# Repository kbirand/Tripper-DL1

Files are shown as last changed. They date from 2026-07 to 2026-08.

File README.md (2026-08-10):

# Tripper Puck (DL1)

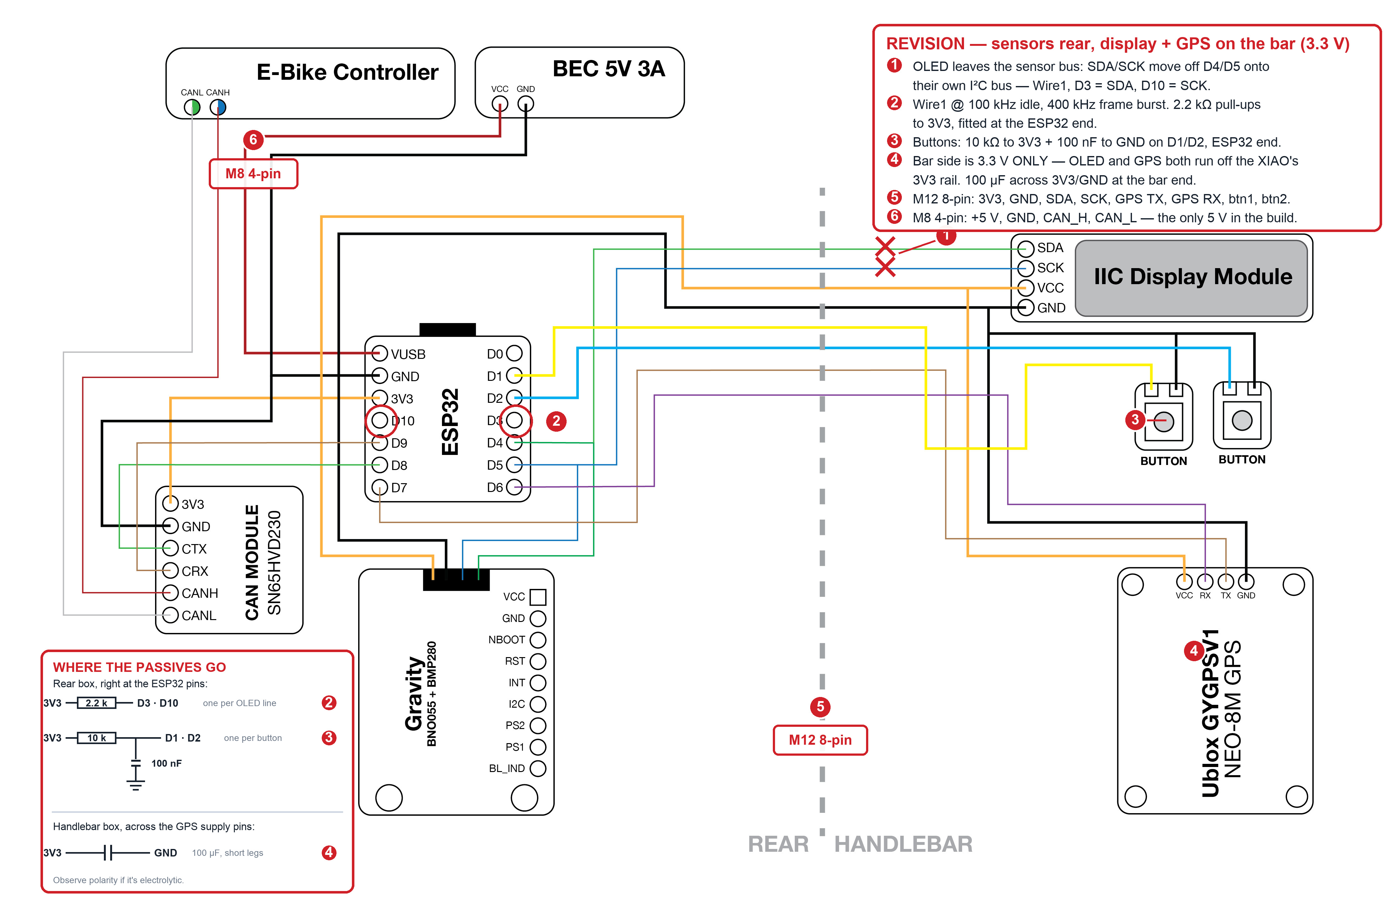
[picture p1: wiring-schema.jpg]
Tripper Puck wiring schematic — ESP32-S3 with the SN65HVD230 CAN transceiver, Gravity 10DOF, NEO-8M GPS, SSD1306 OLED and two buttons, powered from the bike through a 5 V BEC. Split across two enclosures: sensors and CAN at the rear, display, GPS and buttons at the handlebar


The red callouts on the schematic mark the handlebar-split revision — the base
drawing still routes the OLED to D4/D5, which is superseded. Read the notes.

An editable version lives in [`hardware/tripper-puck.fzz`](hardware/tripper-puck.fzz)
(Fritzing). Every part is custom and embedded in the file, so it opens without
installing anything into your parts bin. The nets are the source of truth; the
part placement is machine-generated and worth tidying before you print it.

A matchbox-sized BLE telemetry puck for e-bikes — companion hardware for the
[Tripper iOS app](https://github.com/kbirand/Tripper). It streams on-chip-fused
IMU orientation and barometric data to the phone over Bluetooth LE, and reads
the bike's own CAN bus listen-only for battery, drivetrain and rider-control
data; the app records, analyzes, and exports. The puck itself is stateless: it
powers from the bike through a 5 V BEC and boots in seconds.

It comes in **two builds** that share one codebase and one BLE contract:

- **[Light build](#1--light-build)** — four parts in one box at the rear.
  IMU, barometer and bike CAN. The phone supplies position; the app is the UI.
- **[Full build](#2--full-build)** — adds a handlebar module: 5 Hz GPS, a
  0.91" OLED and two buttons. Strictly additive, so Light upgrades to Full
  without rewiring anything.

See [Choosing a build](#choosing-a-build) for the trade-offs.

**Status:** bench-complete and phone-verified (2026-07-21). Remaining:
Tripper-side `ExternalSensorSource` (Swift), enclosure, field ride.

## How it works

- **No battery** — a 5 V BEC steps the bike's pack down to VUSB; boots with
  the bike
- **No SD card** — the phone is the recorder; BLE is the only data path
- **No screen dependence** — the OLED is a convenience dashboard and every
  feature works headless. The Light build is exactly that claim taken to its
  conclusion: no screen at all, nothing lost from the recording
- **Mount-zero calibration** — the current orientation becomes 0/0/0 (reference
  quaternion, persisted to flash, survives reboots, applied to both display and
  telemetry). Triggered by a 10 s button hold on Full, or *Zero pitch & roll*
  in the app on either build
- **Ride awareness** — the app pushes ride state, so link flaps and mid-ride
  reboots heal themselves. On Full this inverts the OLED and adds a trip-time
  screen; on Light it is simply acknowledged
- **Reads the bike** — listen-only CAN gives battery percentage, pack voltage,
  cell balance, motor current and rider controls without touching the bus

## Choosing a build

Two configurations, one codebase, one BLE contract:

| | **Light build** | **Full build** |
|---|---|---|
| Physical form | one box at the rear | rear box **+ handlebar module** |
| Sensing | IMU, barometer, bike CAN | IMU, barometer, bike CAN, **GPS** |
| Display | none — the app is the UI | **0.91" OLED**, 4 screens |
| Buttons | none — the app sends control writes | **two** (screens · marker/zero) |
| Position from | the **phone's** GPS | the puck's own **5 Hz** GPS |
| Firmware | [`tripper_light`](hardware/firmware/tripper_light/) | [`tripper_puck`](hardware/firmware/tripper_puck/) |
| Parts | 4 | 8 |
| Wires to run | 6 | 14 |

**Start with the Light build.** It is the entire telemetry product — fused
orientation, g-force, barometric altitude and every decoded bike-CAN signal —
in four parts and one enclosure, and your phone already carries a GPS the app
already reads. The Full build buys 5 Hz position (the phone's is 1 Hz), a
dashboard you can read with the phone pocketed, and two hardware buttons.

**The Full build is strictly additive.** Nothing in the Light build gets
rewired to get there: the handlebar parts land on pins the Light build leaves
free, so it is an upgrade path rather than a different project.

The BLE packets are **byte-identical** across both, so the app needs no branch.
A Light puck reports its GPS block as invalid — the same state a Full puck
reports before it gets a fix, which the app already has to handle — and the
status packet's [capability byte](#status-packet-14-bytes) says which build is
on the other end.

## 1 · Light build

MCU, sensor board, CAN transceiver, power. One enclosure at the rear of the
bike; nothing on the handlebar.

| Part | Role |
|---|---|
| Seeed XIAO ESP32-S3 | MCU, BLE 5.0, on-chip TWAI CAN controller |
| DFRobot Gravity 10DOF (BNO055 + BMP280) | On-chip sensor fusion + barometer, I²C |
| SN65HVD230 CAN transceiver | 3.3 V CAN PHY for the bike bus, D8/D9 |
| 5 V BEC (3 A) | Steps the bike's pack down to 5 V, feeds VUSB |

No SD card, no LiPo, no power switch, no status LED, no screen — the phone is
the recorder *and* the interface over BLE, and the bike is the power source.

What you give up versus Full: no on-board position (the app uses phone GPS, so
rides still record), no glanceable display, and marker/mount-zero move to
[control writes](#control-opcodes) instead of buttons.

### Pin map — Light build

| Pin | Function |
|---|---|
| D4 / D5 | I²C SDA / SCL — BNO055 `0x28`, BMP280 `0x76` @ 100 kHz |
| D8 / D9 | CAN TX→CTX / RX←CRX (SN65HVD230), 250 kbit/s listen-only |
| D0, D1, D2, D3, D6, D7, D10 | free — D1, D2, D6, D7 are what the Full build claims |

I²C sits on the XIAO's **default pads**, so a bare `Wire.begin()` would work; the
firmware still names them explicitly via `PIN_SDA`/`PIN_SCL` so the pin map lives
in one place.

> **Troubleshooting — if every I²C device looks dead at once.** The first board
> used in this project had its **D4 pad clamped low**: it read 0 even with the
> internal pull-up enabled and nothing attached, shorted to ground somewhere on
> the board. An I²C line that cannot idle high is a bus no device can ever
> signal on, so it presents as *four* simultaneously dead sensors rather than
> one bad pin — which is why it is worth recognising. SDA was moved to D3 as a
> workaround until the board was replaced.
>
> To tell a dead pad from a wiring fault: pull the pin up, then down, and read
> it back. A pad the chip still controls follows both (1 then 0); one that reads
> 0 against the pull-up is tied to ground by something outside the GPIO.
> `padSweep()` in [`bench_imu_can`](hardware/firmware/bench_imu_can/) does this
> across the whole pad row every boot — one pin failing where six neighbours
> pass is the diagnosis — and
> [`i2c_diag`](hardware/firmware/i2c_diag/) localises it further.

### Wiring — Light build

Pin columns match the physical XIAO ESP32-S3 viewed from above, USB-C at
the top. Six wires plus the two CAN taps:

```
                          USB-C (top edge) — flashing only
                      ┌───────────────────────┐
 n/c ─────────────────┤ D0                 5V ├──◄ BEC +5V ◄─ BEC 5V 3A ◄─ bike pack
 n/c (Full: button 1) ┤ D1                GND ├────────● GND rail ◄ BEC GND
 n/c (Full: button 2) ┤ D2                3V3 ├────────● 3V3 rail
 n/c ─────────────────┤ D3                D10 ├─ n/c
 SDA bus ●────────────┤ D4                 D9 ├──────◄ CAN CRX
 SCL bus ●────────────┤ D5                 D8 ├──────► CAN CTX
 n/c (Full: GPS TX) ──┤ D6 (TX)       (RX) D7 ├─ n/c (Full: GPS RX)
                      └───────────────────────┘
                            XIAO ESP32-S3

 ● 3V3 rail ─┬─ Gravity 10DOF VCC (red)      ● SDA bus (D4) ── Gravity SDA (blue)
             └─ CAN module 3V3
                                             ● SCL bus (D5) ── Gravity SCL (green)
 ● GND rail ─┬─ Gravity 10DOF GND (black)
             └─ CAN module GND

 CAN module CANH ──◄ bike CAN_H          (2-pin connector — see the CAN section)
 CAN module CANL ──◄ bike CAN_L
```

## 2 · Full build

Everything in the Light build, plus a handlebar module: GPS for 5 Hz position,
an OLED for at-a-glance status, and two buttons. The GPS wants sky view and the
screen wants your eyeline, which is why these four live at the bars while the
MCU, sensor board and CAN transceiver stay in the rear box.

| Part it adds | Role |
|---|---|
| u-blox NEO-8M GPS (GYGPSV1 carrier) | 5 Hz position/speed/time, UART @ 115200 |
| SSD1306 0.91" OLED 128×32 | Clock / live-data / bike-CAN screens + all status, I²C `0x3C` |
| 12 mm button | Screen step / auto-cycle toggle |
| HW-483 button | Marker (click) / attitude zero (hold) |

### Pin map — additions

Only free pins are used, so the Light build's wiring is untouched:

| Pin | Function |
|---|---|
| D1 | Screen button → GND (internal pull-up) |
| D2 | Marker/zero button → GND (internal pull-up) |
| D6 / D7 | UART TX→GPS RX / RX←GPS TX @ 115200 |
| D3 / D10 | I²C bus 1 (`Wire1`) SDA / SCL — SSD1306 OLED `0x3C`. **Runs to the handlebar** |

The Light build's D4/D5 bus is untouched and stays **rear-enclosure only**: the
OLED gets its own bus rather than joining it.

**Two I²C buses, on purpose.** The sensors and the display sit in different
enclosures about a metre apart, so they get separate buses. Bus 0 stays short
— 15 cm inside the rear box — because the BNO055's clock-stretching already
forces it to **100 kHz** (validated: 59,722 reads / 0 errors / 10 min) and it
is the one bus whose failure costs real data. Bus 1 carries only the OLED out
to the handlebar; a metre of cable there can glitch the screen but can no
longer touch sensor fusion. Wire1 idles at 100 kHz and bursts frames at
400 kHz (`OLED_BUS_HZ` / `OLED_BURST_HZ` in the firmware) — if a long or
unshielded run tears the display, drop the burst to 100 kHz first.

### Wiring — Full build

Same as the Light build with the handlebar module added. The four new parts land on the
pins the Light build left free, so nothing already wired moves:

Signals marked **⇢ bar** leave the rear enclosure through the 8-pin handlebar
connector; everything else stays inside the rear box.

```
                          USB-C (top edge) — flashing only
                      ┌───────────────────────┐
 n/c ─────────────────┤ D0                 5V ├──◄ BEC +5V ◄─ BEC 5V 3A ◄─ bike pack
 Screen button ⇢ bar ─┤ D1                GND ├────────● GND rail ◄ BEC GND
 Marker/Zero  ⇢ bar ──┤ D2                3V3 ├────────● 3V3 rail
 OLED SDA     ⇢ bar ──┤ D3                D10 ├── OLED SCK  ⇢ bar
 Sensor SDA ●─────────┤ D4                 D9 ├──────◄ CAN CRX
 Sensor SCL ●─────────┤ D5                 D8 ├──────► CAN CTX
 to GPS RX  ⇢ bar ◄───┤ D6 (TX)       (RX) D7 ├──────◄ from GPS TX  ⇢ bar
                      └───────────────────────┘
                            XIAO ESP32-S3

 REAR enclosure                          HANDLEBAR enclosure
 ──────────────                          ───────────────────
 ● 3V3 rail ─┬─ Gravity 10DOF VCC (red)  OLED VCC / GND / SDA / SCK
             ├─ CAN module 3V3           GPS  VCC / GND / TX / RX
             └─── 3V3 ⇢ bar              Screen button ○ ─┐
                                         Marker/Zero   ○ ─┴─ to GND ⇢ bar
 ● Sensor SDA (D4) ── Gravity SDA (blue)
 ● Sensor SCL (D5) ── Gravity SCL (green)   ┌── 100 µF bulk cap across
                                            │   3V3/GND at this end
 ● GND rail ─┬─ Gravity 10DOF GND (black)  ─┘
             ├─ CAN module GND
             └─── GND ⇢ bar

 8-pin handlebar harness (M12 A-coded)
   1 3V3   2 GND   3 OLED SDA (D3)   4 OLED SCK (D10)
   5 GPS RX (◄D6)  6 GPS TX (►D7)    7 btn1 (D1)   8 btn2 (D2)
```

Wiring notes (both builds unless noted):

- **Power comes from a 5 V BEC**, not USB. The BEC steps the bike's traction
  pack down to 5 V / 3 A and feeds the XIAO's 5V (VUSB) pin. USB-C is only for
  flashing — **never plug USB in while the BEC is powered**: both drive VUSB
  and the two 5 V rails collide. Unplug one before the other.
- **GPS UART is a crossover** *(Full only)* — XIAO TX (D6) feeds the GPS **RX**
  pin and vice versa. If the firmware reports "no NMEA data", these two are
  swapped. Note the CAN pair on D8/D9 is *not* a crossover: CTX→CTX, CRX→CRX.
- **Buttons need external pull-ups now that they're a metre away** *(Full
  only)*. Each still connects its pin straight to GND and the firmware still
  enables the internal pull-up — but that pull-up is ~45 kΩ, and a metre of
  wire on a high-impedance input is an antenna for BEC and motor-controller
  switching noise. Add a **10 kΩ to 3V3 and a 100 nF to GND at the ESP32 end**
  of D1 and D2. On a breadboard with short leads you can skip this; on the bike
  you cannot.
- **The Gravity board's I²C comes from its 4-pin socket** (its back-side
  pad row is control pins only — no SDA/SCL there). Trim the cable to
  length and glue-lock the connector for vibration.
- **The handlebar box is 3.3 V only.** Both things in it — the SSD1306 and the
  NEO-8M carrier — run off the XIAO's own 3V3 regulator; the only 5 V anywhere
  in the build is the BEC feeding VUSB inside the rear box. Never run 5 V up to
  the bar. This also raises the stakes on the two rules below: there is no
  regulator at the far end to absorb cable drop, so whatever the metre of wire
  loses comes straight out of the GPS's supply margin.
- **The handlebar run** carries 8 conductors (see the harness table above) over
  roughly a metre. Rules for it:
  - **Shielded multicore**, shield to GND **at the rear end only** — grounding
    both ends makes a loop.
  - **SDA and SCL each twisted with their own GND return**, never twisted with
    each other; paired together they crosstalk. Same for GPS TX/RX.
  - **2.2 kΩ pull-ups on the OLED bus**, fitted at the ESP32 end, replacing the
    module's own 4.7–10 kΩ. A metre of cable adds ~100 pF and the weaker
    pull-ups can't pull the edges up through it. Sizing, if your run is longer:
    the pull-up and the bus capacitance set the rise time, which must stay under
    1 µs at 100 kHz, while the sink current (3.3 V ÷ R) must stay under 3 mA.

    | Run | Bus C | 2.2 kΩ | 1.5 kΩ |
    |---|---|---|---|
    | 1 m | ~150 pF | 0.27 µs | 0.19 µs |
    | 2 m | ~250 pF | 0.7 µs | 0.45 µs |
    | 3 m | ~350 pF | 1.2 µs ✗ | 0.63 µs |

    So **2.2 kΩ to ~2 m, 1.5 kΩ (2.2 mA sink) to ~3 m.** Past 3 m the 400 pF
    bus-capacitance ceiling binds and no pull-up value saves it.
  - **100 µF bulk capacitor at the handlebar end**, across 3V3/GND near the GPS.
    Its acquisition current spikes into the cable's inductance otherwise sag
    the rail and lengthen time-to-fix.
  - **≥ 26 AWG** on the 3V3 and GND conductors. The bar end draws ~60 mA, which
    is only ~16 mV of drop at 26 AWG — but thin 30 AWG hookup wire more than
    doubles that, and it comes off a 3.3 V rail with no headroom to spare.
  - **Past 2 m, drop `OLED_BURST_HZ` to 100 kHz** and move to the 1.5 kΩ
    pull-ups. Don't reach for an I²C buffer (P82B715 / P82B96) — the arithmetic
    above says plain I²C covers any run a motorcycle actually needs, and both
    parts are out of stock domestically anyway (the P82B715 is obsolete).
  - **Keep the cable thin.** 8 × 0.14 mm² (≈26 AWG) shielded is ~6 mm OD and
    still flexible; 0.25 mm² and up gets stiff enough to fatigue at the steering
    head. 0.14 mm² carries the ~60 mA with room to spare.
- **GPS patch antenna**: sky-facing, ≥ 15 mm from the XIAO and USB cable —
  the ESP32's RF noise measurably delays fixes. Moving the GPS to the handlebar
  enclosure satisfies this for free, since the ESP32 stays at the rear.
- **GPS backup cell** (MS621 on the GY carrier): if it's flat, every power
  cycle factory-resets the module to 9600/1 Hz *and* forces a cold start
  (minutes to first fix instead of seconds). The firmware detects the revert
  and reconfigures automatically — boot log says `was at 9600 factory: BBR
  lost, check backup cell` — but only a healthy cell brings back hot starts.
  The cell trickle-charges while powered; if it never holds, replace it.

### Connectors

Two enclosures means two harnesses, and they are deliberately different sizes
so they cannot be cross-plugged.

| Run | Conductors | Connector |
|---|---|---|
| Bike → rear enclosure | +5 V, GND, CAN_H, CAN_L | **M8 4-pin**, IP67 |
| Rear → handlebar enclosure | **3V3**, GND, SDA, SCL, GPS TX, GPS RX, btn1, btn2 | **M12 8-pin A-coded**, IP67 |

The two runs carry different voltages — 5 V to the rear box, 3.3 V onward to the
bar — which is a second reason the connectors are deliberately different sizes.

**Gender follows the live side.** Whichever end stays energised when the pair
is separated gets the *female* sockets — recessed contacts can't be shorted
against the frame. On the bike run that's the cable (it goes back to the BEC),
so the rear enclosure carries a **male** panel receptacle and the cable carries
a **female** plug. The handlebar run is dead on both sides once the bike
connector is pulled, so either orientation is safe there; keep the panel male
for consistency.

Parts that work, sourced domestically (prices July 2026): rear panel
**ATTEND 219A-04MSR** ≈ ₺243, bike cable **SIGNAL ASM08AF04001** ≈ ₺282. If you
also want the BEC and CAN tap to separate from the 4-core, add
**ASM08AM04001** + a second **ASM08AF04001** — but note these field-assembly
bodies take a *single* cable gland, so the BEC pair and CAN pair must be merged
into one jacket before the connector either way. Unless that junction needs to
come apart, solder and adhesive-lined heat-shrink is more vibration-tolerant
and free.

**Keep the pin assignment identical at both ends of every run.** With two
connectors in the harness it is easy to mirror one and feed 5 V into CAN_H.

## Firmware

Arduino sketches in [`hardware/firmware/`](hardware/firmware/):

| Sketch | Purpose |
|---|---|
| [`tripper_light`](hardware/firmware/tripper_light/) | **Light-build firmware** — IMU + baro + CAN → BLE. No GPS/OLED/button code at all; marker and mount-zero arrive as control writes. Same UUIDs and same 88-byte packet as the Full build |
| [`tripper_puck`](hardware/firmware/tripper_puck/) | **Full-build firmware** — sensors + GPS → BLE + OLED |
| [`bench_imu_can`](hardware/firmware/bench_imu_can/) | Bring-up rig for a half-built puck — IMU + baro + CAN only, no OLED/buttons/GPS. Talks to the BNO055 registers directly (a library `begin()` can't tell a phantom ACK from a chip), counts every failed read, and re-probes missing sensors every 3 s so a wire soldered mid-run comes up on its own. Same BLE UUIDs and packets as production |
| [`i2c_gate`](hardware/firmware/i2c_gate/) | BNO055 clock-stretch stress test (the go/no-go gate) |
| [`i2c_diag`](hardware/firmware/i2c_diag/) | Wiring diagnostic — line states + normal/swapped bus scans |
| [`gps_config_5hz`](hardware/firmware/gps_config_5hz/) | One-time GPS config: 5 Hz + 115200, saved to BBR (production firmware re-applies at boot) |
| [`gps_revert_factory`](hardware/firmware/gps_revert_factory/) | Test harness — reverts the GPS to 9600/1 Hz factory defaults (simulates a power cycle with a dead backup cell) to exercise `gpsBringup()`'s recovery path |
| [`can_probe`](hardware/firmware/can_probe/) | CAN bring-up — decoded dashboard on the OLED and over BLE (`Tripper-CAN`, Nordic UART). Reports wirelessly on purpose: the bike and a USB host must never be connected at once |

### Build & flash

```sh
arduino-cli core install esp32:esp32

# Light build — no SSD1306 or TinyGPSPlus needed
arduino-cli lib install "Adafruit BNO055" "Adafruit BMP280 Library" "NimBLE-Arduino"
arduino-cli compile -b esp32:esp32:XIAO_ESP32S3 hardware/firmware/tripper_light
arduino-cli upload  -b esp32:esp32:XIAO_ESP32S3 -p /dev/cu.usbmodem* hardware/firmware/tripper_light

# Full build — adds the display and GPS libraries
arduino-cli lib install "Adafruit SSD1306" "TinyGPSPlus"
arduino-cli compile -b esp32:esp32:XIAO_ESP32S3 hardware/firmware/tripper_puck
arduino-cli upload  -b esp32:esp32:XIAO_ESP32S3 -p /dev/cu.usbmodem* hardware/firmware/tripper_puck
```

USB is needed exactly twice in a puck's life — the first flash of an
OTA-capable firmware, and recovery if an update bricks it. After that the puck
raises its own WiFi network on request and can be flashed from a laptop *or
straight from a phone browser* with the bike untouched; the last built image is
committed at [`releases/`](releases/) so no toolchain is needed at all.
**[`docs/flashing.md`](docs/flashing.md) is the complete reference** —
networks, passwords, both command lines, making a `.bin`, and which of the nine
build artifacts is the one you flash.

⚠️ **Never plug USB in while the BEC is powered, and never while the CAN pair
is spliced in** — see [Bike CAN bus](#bike-can-bus-talaria). Unplug the 2-pin
CAN connector or kill the BEC before flashing.

The two sketches keep duplicate copies of the packet structs, the CAN decode
and the UUIDs. That is deliberate — each is a standalone Arduino sketch — but
it means the two can drift. Anything touching the wire format must land in
both; this check should print nothing:

```sh
for f in tripper_puck tripper_light; do
  awk '/^struct __attribute__\(\(packed\)\) TelemetryPacket/,/^static_assert\(sizeof\(StatusPacket\)/' \
    hardware/firmware/$f/$f.ino | grep -E "^\s+(uint|int)[0-9_]+t\s" | sed 's|//.*||;s/[[:space:]]*$//' > /tmp/$f.f
done; diff /tmp/tripper_puck.f /tmp/tripper_light.f && echo "packets agree"
```

### Controls — Full build only

| Input | Action |
|---|---|
| Screen button (D1) click | Step to the next OLED screen |
| Screen button (D1) 3 s hold | Toggle auto-cycling (thin border = cycling) |
| Marker button (D2) click | Marker counter++ in telemetry · MARK splash |
| Marker button (D2) 10 s hold | Zero the mount at the current orientation (progress bar → ZEROED, or `ACC n/3` if the accelerometer isn't calibrated yet) |

The Light build has no buttons and no screen: markers arrive as control write
`0x01` and mount-zero as `0x02`, both from the app. Everything below describes
the Full build's display.

All status lives on the OLED. **Screens do not rotate on their own** — on a
moving bike the screen you picked should stay put, so D1 steps through them
and only a 3 s hold hands the stepping back to a 5 s timer (thin border while
it does). Three screens normally:

1. **Clock** — GPS time, UTC+3
2. **Data** — GPS speed hero, roll/pitch, satellites, g, fix dot, link state
3. **Bike CAN** — wheel speed hero, battery percentage, ride mode, kickstand;
   reads `no data` when no CAN frame has arrived in 2 s, `off` if the TWAI
   controller never came up

While the app is recording a ride the display runs inverted and a fourth
screen joins: the trip time (app-authoritative, so it tracks pauses and
survives reconnects). It disappears when the ride ends, and the screen index
falls back to the clock if it was showing.

## BLE protocol

Device name `Tripper-DL1`. One service, four characteristics:

| UUID | Char | Direction |
|---|---|---|
| `8E7C1A20-0F5A-4B9C-9C90-54B1D2A70001` | *service* | |
| `…0002` | telemetry | notify + read, 5 Hz, 92 B |
| `…0003` | status | notify + read, 1 Hz, 15 B |
| `…0004` | control | write / write-no-response |
| `…0005` | raw | notify, 10 Hz, 148 B — the un-averaged 100 Hz IMU stream |

### Telemetry packet (86 bytes, little-endian, packed)

| Offset | Type | Field | Notes |
|---|---|---|---|
| 0 | u8 | ver | `0x05` — byte-identical *layout* to `0x04`; the bump marks a semantics change (see `gyr`/`acc` below). `0x03` was the 78-byte packet with no raw accelerometer, `0x02` the 70-byte one with no IMU health, `0x01` the 50-byte pre-CAN one |
| 1 | u8 | flags | bit0 fix valid · bit1 time valid · bit2 IMU calibration usable |
| 2 | u32 | gpsTimeMs | UTC ms-of-day, `0xFFFFFFFF` if invalid |
| 6 | i32 | lat_e7 | degrees × 1e7 |
| 10 | i32 | lon_e7 | degrees × 1e7 |
| 14 | i32 | alt_cm | GPS altitude |
| 18 | i32 | baroAlt_cm | BMP280, std-atmosphere ref |
| 22 | u32 | press_pa | pressure |
| 26 | u16 | speed_cmps | cm/s |
| 28 | u16 | course_cdeg | degrees × 100 |
| 30 | u8 | sats | used in fix |
| 31 | u16 | hdop_c | HDOP × 100 |
| 33 | i16×4 | qw qx qy qz | quaternion × 16384, **mount-zeroed** |
| 41 | i16×3 | lin x y z | linear accel, mg (sensor frame) |
| 47 | i16 | maxG_mg | interval max \|lin\|, resets each packet |
| 49 | u8 | marker | increments per button press |
| 50 | u8 | canFlags | bit0 live · bit1 kickstand down · bits3:2 ride mode (1 Eco, 2 Sport) · bits6:4 regen level 1–4 (0 = unknown) |
| 51 | u16 | canSpeed_dkph | 0.1 km/h |
| 53 | u16 | canRpm | motor rpm |
| 55 | u16 | canPower_w | watts |
| 57 | u16 | canCurrent_da | 0.1 A |
| 59 | u16 | canPack_dv | 0.1 V |
| 61 | u8 | canSoc_pct | battery percentage |
| 62 | u16 | canDemand | throttle demand, units unconfirmed |
| 64 | u16 | cellHi_mv | highest cell, mV |
| 66 | u8 | cellHi_idx | its index, 1–16 |
| 67 | u16 | cellLo_mv | lowest cell, mV |
| 69 | u8 | cellLo_idx | its index, 1–16 |
| 70 | i16×3 | gyr x y z | gyro, deg/s × 16 (sensor frame). **`0x05`: the mean of the 200 ms window**, not the newest 100 Hz sample |
| 76 | u8 | calib | bits 7:6 sys · 5:4 gyro · 3:2 accel · 1:0 mag, each 0–3 |
| 77 | u8 | zeroCount | mount zeros the puck has **accepted** since boot |
| 78 | i16×3 | acc x y z | **raw** accelerometer, mg (sensor frame) — gravity included, pre-fusion. **`0x05`: window mean**, as `gyr` |
| 84 | u16 | quatRejects | non-unit `getQuat()` reads dropped since boot, saturating |
| 86 | u16 | accDev_mg | **`0x06`:** largest \|‖a‖ − 1 g\| seen at 100 Hz inside this window, mg — the peak the `acc` mean cannot show |
| 88 | u32 | canOdo_km | **`0x07`:** the bike's odometer, whole km, from CAN `0x402[2:4]`. 0 means not seen yet |

Bytes 50–69 are the bike's CAN bus, read listen-only from a SN65HVD230 on
D8/D9 (see [Bike CAN bus](#bike-can-bus-talaria)). **The whole block is zeroed
and `canFlags` bit0 is clear whenever no frame has arrived in the last 2 s** —
transceiver unplugged, bike asleep, or bus fault. Gate every CAN field on that
bit rather than trusting a zero speed, or a parked bike and a disconnected
cable look identical.

Note `speed_cmps` at offset 26 is GPS ground speed in cm/s; `canSpeed_dkph`
at 51 is the bike's own wheel speed in 0.1 km/h. They are independent
measurements and will disagree — wheelspin, GPS lag, tyre circumference.

Bytes 70–77 are IMU health, appended *after* the CAN block so every `0x02`
offset stays byte-identical and an older app keeps parsing. They exist because
raw gyro and calibration used to stay on the puck — which is why a lean fault
took a GPS cross-check to diagnose rather than a look at the recording. `mag` is
always 0: IMUPLUS never turns the magnetometer on. See
[IMU calibration](#imu-calibration) for what the numbers mean.

`zeroCount` exists because the mount zero is a fire-and-forget control write
that the puck is allowed to refuse — so "the rider tapped the button" and "the
puck re-referenced itself" are different facts, and on a Light build there is no
screen to tell them apart. It increments only on a zero the puck **accepted**.
Watch for a *change* against the value you held when you sent `0x02`, never for
a particular number: it wraps at 255 and restarts at 0 on reboot.

Bytes 78–85 are the **raw accelerometer** and the quaternion-reject count, and
they exist because everything above them that bears on attitude — the
quaternion, the linear accel, even the calibration byte — is a *product* of the
BNO055's fusion. When the fusion itself is the suspect, those fields agree with
each other by construction, whatever they say. A ride that read −10° of lean
down a dead-straight road ruled out the mount, the axes, the zero, gyro drift,
the bike's own acceleration and vibration, then ran out of evidence, because
every remaining witness was the accused.

`acc` is the pre-fusion measurement: gravity plus motion, straight off the
sensor, in the sensor frame and deliberately not rotated by anything.
**`acc − lin` is the fusion's own gravity vector** — compare its direction
against the quaternion, and against the low-passed direction of `acc` itself,
and "is the chip fed bad data, or mishandling good data" becomes answerable
from a recording. `quatRejects` should stay flat; a count that climbs mid-ride
means the attitude is being *held* across glitched I2C reads rather than
tracking the bike.

**Why `0x06` adds a peak beside the mean.** Averaging is what makes `acc`
usable as a direction, and it is also what makes it useless as a *warning*.
The app's estimator only takes its "down" reference from the accelerometer
while `‖a‖` is near 1 g — braking bumps and drops point it somewhere that
isn't down — but it was applying that test to the window mean, which is the
one number that cannot reveal a jolt inside its own window. The 100 Hz flight
recorder settled it on the 2026-08-09 rides: the real `‖a‖` was outside
0.8–1.2 g on **17–20% of moving samples**, while the means were outside on
**0.6–1.3%**. The gate had been tuned against a signal already smoothed into
compliance and was passing almost everything it exists to refuse. A mean
cannot be un-averaged, so the peak is taken here, where the samples are.

Note this is *not* `maxG_mg`, which latches the peak of the fusion's linear
acceleration — a product of the very fusion `acc` exists to cross-check.

**Why `0x05` averages.** Through `0x04` these two fields carried whichever
100 Hz sample happened to land when the packet was built — 1 in 20 reached the
app and the other 19 were discarded, so a single vibration spike could be the
one that got through. `0x05` sends the mean of all 20 instead. The layout did
not move a byte, which is why an app that ignores the version still parses it.

That fixed the spikes and introduced a subtler problem: a mean is a boxcar
filter, and a boxcar has a first sidelobe only 13 dB down. Suspension
resonance (2–5 Hz) and wheel hop (10–20 Hz) are above the 2.5 Hz Nyquist of a
5 Hz output, so they **alias** into the road-grade band rather than being
removed, and no amount of downstream filtering can separate them again. That
is what the raw characteristic below exists for.

### Status packet (15 bytes)

`ver u8 · fix u8 · sats u8 · battPct u8 (0xFF = external supply) · hdop_c u16 ·
uptime_s u32 · temp_x10 i16 · marker u8 · caps u8 · otaState u8`

The last byte was `reserved` (always 0) and now carries **capability bits**, so
the app can tell the builds apart — chiefly to know whether it must supply
position from the phone:

| Bit | Meaning | Light | Full |
|---|---|---|---|
| `0x01` | has GPS | — | ✅ |
| `0x02` | has OLED | — | ✅ |
| `0x04` | has buttons | — | ✅ |
| `0x08` | has CAN | ✅ | ✅ |

So Light sends `0x08` and Full sends `0x0F`. **A value of `0` means firmware
older than this field**, not "no capabilities" — which is why `has CAN` is an
explicit bit rather than assumed.

`otaState` (byte 14) reports WiFi flashing mode as the puck actually has it,
not as the app last asked for it: `0` off · `1` network up with no client ·
`1+n` with n clients joined. The app's toggle reads this back so it shows the
truth after a reconnect, and the mode never survives a power cycle. Length-gate
it — a 14-byte status packet is older firmware, not `otaState = 0`.

### Raw stream (148 bytes per batch, little-endian, packed)

The flight recorder: the 100 Hz IMU samples themselves, no averaging. Ten per
notification, ten notifications a second — about 1.5 kB/s against the 185 B ATT
MTU iOS negotiates, so one batch is one notification.

| Offset | Type | Field | Notes |
|---|---|---|---|
| 0 | u8 | ver | `0x01` |
| 1 | u8 | count | RawSamples following the header (10) |
| 2 | u16 | period_us100 | nominal sample period, units of 100 µs (`100` = 10 ms) |
| 4 | u32 | t0_ms | **puck** millis at the first sample in this batch |
| 8 | i16×4 | qw qx qy qz | the BNO055's own fusion quaternion, ×16384, **unzeroed** |
| 16 | i32 | press_pa | raw pressure — *not* converted altitude |
| 20 | i16 | temp_x10 | °C × 10 |
| 22 | u8×4 | calSys calGyr calAcc calMag | 0–3 each |
| 26 | u8×2 | pad | |
| 28 | i16×6 | gx gy gz ax ay az | ×10 samples: gyro deg/s × 100, accel mg |

**`t0_ms` is the whole point of the header.** BLE delivers in bursts, so the
phone's arrival time is not when the sample was taken. At 5 Hz nobody noticed;
at 100 Hz it would corrupt every derivative computed downstream. Reconstruct
the timeline from the puck's own counter and the nominal period, and use the
phone's clock only to anchor the start of the ride.

Everything here is **raw and un-decided**: pressure rather than altitude
because the conversion is lossy, the quaternion unzeroed because the mount
reference is an app-side convention that may be re-derived later, and samples
rather than means because a mean cannot be un-averaged. The chip's own fusion
is logged even though it was convicted (see
[`docs/data-quality-audit.md`](docs/data-quality-audit.md)) on the grounds that
a verdict nobody can re-test is an opinion.

The stream is **additive**: a phone that never subscribes sees the puck behave
exactly as it did before the characteristic existed.

### Control opcodes

| Byte | Payload | Action |
|---|---|---|
| `0x01` | — | **Full:** marker ack — MARK splash on the OLED (the button already counted it). **Light:** originates the marker, incrementing the counter — there is no button |
| `0x02` | — | Zero the mount at the current orientation — same as the 10 s button hold on Full, the only way to do it on Light. Saved to flash on both. Refused while accel calibration is under 3/3 |
| `0x03` | — | Identify — **Full:** OLED inverts for 2 s. **Light:** accepted and logged, no indicator to flash |
| `0x04` | `active u8 · elapsed_s u32` | Ride state — **Full:** inverts the OLED and adds the trip-time screen, elapsed seeds the timer. **Light:** accepted and logged, no display. The app re-sends it on every reconnect |
| `0x05` | `on u8` | WiFi flashing mode — raises the puck's own SoftAP for OTA and the diagnostics/`/update` web server. Never persists across a power cycle. Live state comes back in `otaState`. See [`docs/flashing.md`](docs/flashing.md) |
| `0x06` | `on u8` | Raw 100 Hz stream on/off. **Boots on** — every ride should be a regression test, and the phone decides whether to keep the bytes. The switch is there for the day a link problem needs the radio quiet |
| `0x07` | `mode u8` | **Ride-mode override** (ver `0x07`) — 0 releases · 1 Eco · 2 Sport. Held by answering each of the dash's `0x490` frames with the overridden value |
| `0x08` | `level u8` | **Regen override** (ver `0x07`) — 0 releases · 1–4 selects. Nothing can confirm it took, and the bike inhibits regen above ~90% SOC where it correctly does nothing |

Both builds accept all eight opcodes, so the app never has to withhold a write.

### Overriding the bike — what `0x07` and `0x08` actually do

Until ver `0x07` this puck could not transmit at all. It now does, and the two
rules that make that safe are worth stating outright.

**An override is a standing argument, not a command.** `0x490` is the dash's
mode/regen command to the motor controller, the controller obeys whichever copy
it heard *last*, and it never latches — so the dash's next frame, 200 ms later,
undoes anything sent once. The puck therefore answers **every** `0x490` the dash
sends, immediately, for as long as an override is held. Bench-measured
2026-08-10: replying on receipt held the controller on **297/297** of its own
frames, where a free-running 20 Hz injection lost 24%. Latency is the mechanism,
not rate.

**Every failure path releases.** BLE disconnect, CAN going stale, and the rider
pressing the handlebar button all drop the override, and the bike is back under
the dash's control within 100 ms of the last frame the puck sends. The
handlebar-button rule matters most: without it software could hold a mode the
rider is actively pressing to leave, and the only escape would be finding the
phone.

The puck reports what it is actually holding in the status packet's `ovrState`,
which is not an echo of the request — an override can end without the app doing
anything, so the app must render the report rather than its own intent.

**The bike's own screen will disagree.** The dash never listens to the bus; it
displays its own selection. While an override is held the display and the
machine genuinely differ, and no firmware change can fix that from this side.

### More than one app at a time

The puck accepts up to **3 simultaneous connections** (`CONFIG_BT_NIMBLE_MAX_CONNECTIONS`),
but until 2026-08-10 it served exactly one. A BLE peripheral stops advertising
the moment it accepts a connection, and while `advertiseOnDisconnect(true)`
brought it back when a device *left*, nothing ever restarted it on connect —
so a second app could never find the puck. `onConnect` now resumes advertising
while there is room.

The CCCD budget is 8. Tripper subscribes to 3 characteristics and the dashboard
app to 2 — which is exactly why the dashboard leaves the raw stream alone. Two
apps spend 5 of 8; a third full subscriber would reach the ceiling.

An override belongs to the **connection that requested it** and is released when
that connection drops, not when any client happens to disconnect. Otherwise one
app leaving would silently cancel another's override.

## IMU calibration

Both builds run the BNO055 in `OPERATION_MODE_IMUPLUS` — six-axis, no
magnetometer. That is the right choice on a motorcycle (a steel frame and a
motor make magnetometer calibration junk, and heading comes from GPS anyway),
but it has a consequence worth stating plainly:

> **In IMUPLUS the accelerometer is the only thing that knows where down is.**
> Every lean and slope number the puck produces is anchored to it. An
> uncalibrated accelerometer doesn't fail loudly — it biases attitude quietly,
> for the whole ride.

So the firmware now:

- calls `setExtCrystalUse(true)`. The Gravity board carries a 32.768 kHz
  crystal; without this the fusion runs on the internal RC oscillator, which
  Bosch does not consider adequate for the fusion modes
- reads `getCalibration()` at 1 Hz and puts it in the telemetry packet
- **refuses a mount zero while the IMU is uncalibrated** — the OLED shows
  `ACC n/3` instead of `ZEROED`, and the app disables its zero button and says
  why (a Light puck has no screen, so the app is the only place it can)
- saves the offsets to flash the first time calibration reaches 3/3 and restores
  them at every boot
- rejects any `getQuat()` that isn't a unit quaternion, counting the drops as
  `qrej` in the serial line — a climbing count means the I²C run is marginal

**Calibrating from cold:** leave the bike still and upright on level ground for
a few seconds. Accelerometer and gyro both settle without any waving about —
that dance is for the magnetometer, which this mode never uses. Watch `cal=` in
the serial debug line, or the app's *IMU calibration* row. It is a once-per-chip
chore, not once-per-ride, because the offsets persist.

> **`cal=` reads 0 for accel after every reboot, even on a calibrated chip.**
> The BNO055's `CALIB_STAT` reports the fusion's *live* confidence, not whether
> offsets are loaded — restoring them does not restore the status byte. So
> nothing gates on `cal` directly: the firmware tracks whether it restored
> offsets from flash, and publishes the verdict as **flags bit2**. That is what
> the app's zero button follows. Gating on `cal` alone would refuse a zero after
> every power-up, which on a Light puck (no buttons, no screen) would leave no
> way to zero at all.

**Reading the debug line** — `cal=321` is sys 3, gyro 2, accel 1. Only the last
two matter here; `sys` stays low in IMUPLUS and is not a fault. `gz=` is the raw
yaw rate: on a straight road it should sit near zero, and a steady non-zero
reading is gyro bias, which is what makes attitude wander.

## Bike CAN bus (Talaria)

The bike's own CAN bus carries battery and drivetrain data the puck's sensors
can't see — pack voltage, cell balance, motor current, state of charge. **Both
builds** read it listen-only and append it to the BLE telemetry packet — CAN is
in the rear box, so it is part of the Light build, not an upgrade;
[`tools/`](tools/) holds the host-side bring-up and reverse-engineering
kit that produced the decode.

**Hardware:** a 3.3 V **SN65HVD230** transceiver on D8 (GPIO7 → CTX) and
D9 (GPIO8 → CRX), CANH/CANL to the bike. Straight through, *not* a crossover
like the GPS UART. No ground wire is needed in the CAN tap — the puck and the
bike already share a ground through the BEC's negative rail. The ESP32-S3's own
TWAI controller is the CAN peripheral, so the module is only a physical layer.

**Remove the module's onboard 120 Ω terminator** (marked `121`, sitting across
CANH/CANL). The bike's bus is already terminated at both ends and reads 60 Ω;
a third resistor drops it to 40 Ω.

**Never connect USB and the bike at once.** Once CANH/CANL are spliced in, the
puck's ground *is* the bike's ground (shared through the BEC). Attaching a
mains-earthed host then ties the bike's battery negative to protective earth,
and USB 5 V collides with the BEC's 5 V on VUSB. **Unplug the 4-pin bike
connector before you attach USB** — it carries +5 V, GND, CAN_H and CAN_L
together, so pulling it isolates both hazards at once. (It replaces the 2-pin
CAN-only break earlier revisions called for; one connector, one action, nothing
to forget.) Read telemetry over BLE instead.

**250 kbit/s, standard 11-bit IDs, 15 messages, ~92 frames/s.** Tap CAN_H and
CAN_L at the controller. A healthy bus reads 60 Ω across the pair with the
bike **off** (two 120 Ω terminators in parallel); 120 Ω means you're on one
end only. If the adapter has a 120 Ω termination jumper, pull it — the bus is
already terminated at both ends and a third resistor drops it to 40 Ω.

Everything defaults to **listen-only**: the transceiver never drives the bus
and never even ACKs, so a wrong bitrate cannot disturb the bike.

```sh
python3 -m venv .venv && ./.venv/bin/pip install -r tools/requirements.txt
./.venv/bin/python tools/can_sniff.py scan   -p /dev/cu.usbserial-510
./.venv/bin/python tools/can_sniff.py sniff  -p /dev/cu.usbserial-510 -b 250000
./.venv/bin/python tools/can_sniff.py events -p /dev/cu.usbserial-510 -b 250000
```

| Command | Purpose |
|---|---|
| `scan` | Sweeps bitrates × STD/EXT and reports which decodes traffic. Zero frames everywhere usually means CAN_H/CAN_L are swapped — harmless, just swap them |
| `sniff` | Live table: decoded physical values, per-ID rates, per-byte change map |
| `events` | Learns which bytes drift on their own, then prints only real changes. Operate one control at a time to find what carries it |
| `log` | Records to `.asc` / `.blf` / `.csv` for offline analysis |

### Decoded signals

Full provenance for each — how it was verified and what was ruled out — is in
the `CM_` comments of [`tools/talaria.dbc`](tools/talaria.dbc).

| Signal | Frame | Bytes | Scale |
|---|---|---|---|
| Speed | `0x303` | 0–1 LE | 0.1 km/h |
| Motor RPM | `0x203` | 0–1 LE | 1 rpm |
| Power | `0x203` | 2–3 LE | 1 W |
| Current | `0x302` | 4–5 LE | 0.1 A |
| Pack voltage | `0x101` | 0–1 LE | 0.1 V |
| Battery percentage | `0x401` | 0 | 1 % |
| Highest cell + index | `0x201` | 0–1 LE, 4 | 1 mV |
| Lowest cell + index | `0x201` | 2–3 LE, 5 | 1 mV |
| Kickstand | `0x202` | byte 0 bit 7 | 1 = down |
| Ride mode | `0x202` | byte 0 bits 5:4 | 1 Eco, 2 Sport |
| Regen level | `0x490` | byte 0 bits 2:0 | 1–4 |
| Ride mode (dash command) | `0x490` | byte 0 bits 5:3 | 1 Eco, 2 Sport |
| Odometer | `0x402` | 2–3 LE | 1 km |
| Throttle demand | `0x202` | 3–4 LE | units unconfirmed |

Speed and RPM hold a fixed 5.887 ratio at r = 0.999 across two independent
rides; integrating speed reproduces plausible ride distances. Cell high/low
averaged × 16 reproduces pack voltage to 0.02 V, confirming the 16S pack.

Traps worth knowing:

- **`0x103[0]` is not the battery percentage.** It reads a constant 100 while
  actual charge is elsewhere — almost certainly state of *health*.
- **`0x202[6:8]` is not an odometer.** It is monotonic, which is why it looks
  like one, but its rate has correlation −0.0005 with speed and its counts per
  km differ 34% between rides. **The odometer is `0x402[2:4]`**, whole km — see
  below.
- **The bus carries 15 IDs; this firmware kept 8.** "No odometer has been found
  on the bus" stood here for months and was false: it had been concluded from
  the eight frames the puck captures, and `0x402` was one of the seven nobody
  had ever decoded. Found 2026-08-10 by reading the odometer off the bike's own
  display (400 km) and looking for that number in a full-bus capture — `0x402
  [2:4]` read exactly 400. **Provisional** until a ride shows it incrementing:
  this bus carries round constants (1200 sits in both `0x101[4:6]` and
  `0x302[6:8]`), so one static match against a round number is suggestive, not
  proof. The lesson generalises — capture every ID, not the ones you decode,
  and when the vehicle already displays a number, use it as ground truth.
- **`0x490[0]` is not a temperature, and it is not one field.** Bits 5:3 carry
  the ride mode (r = 0.99, which is why the whole byte looked like mode alone)
  and bits 2:0 carry the regen level. Reading the low *nibble* as regen works
  only in Sport: in Eco bit 3 is set, so regen 1 reads `0x09` rather than
  `0x01`. Mask 3 bits, not 4.
- **`0x490` is a COMMAND from the dash, not an echo from the controller.** It
  was labelled an echo until 2026-08-10. Across five button presses `0x490[0]`
  moved *first* every time, with `0x202` following 20–27 ms later carrying both
  the new mode bits and the new demand floor (Sport 1100 / Eco 750). Injecting
  `0x490` with Eco, while the dash went on sending Sport at 5 Hz, held the
  controller at `demand=750` for the whole burst — so the controller obeys the
  bus, and `0x202` and `0x490` are different nodes. Consequences if you ever
  want to *control* one of these bikes: the controller follows the most recent
  `0x490` and never latches, so an override must out-transmit the dash
  continuously (free-running at 20 Hz still lost 24% of the time; replying the
  instant the dash speaks held 297/297); the dash never listens, so an
  overridden bike disagrees with its own screen; and regen can be commanded but
  **not verified from anywhere** — it moves nothing else on the bus, and regen
  current is unmeasurable because power and current are unsigned.
- **Byte offsets vary by firmware.** Throttle demand sits at `0x202[3:5]` here
  but at `0x202[2:4]` on the bike in the reference logs, where it doesn't
  track throttle at all. Verify offsets before trusting this on another bike.

Horn and lights never reach the bus — they're switched 12 V circuits from the
bar switchgear. Brake levers appear on some bikes; aftermarket levers without
sensors produce nothing.

DBC groundwork from [inklit/Talaria_CAN](https://github.com/inklit/Talaria_CAN),
whose two ride logs were the reference data for every decode above.

## Docs

The full build story — shopping list (Turkey), decision records, validation
results, pitfalls — lives in [`hardware/build-guide.html`](hardware/build-guide.html).

What the **app** side has to do differently — the capability byte, the regen
level, gating on `canFlags`, and why `battPct` is a sentinel rather than a
reading — is in [`docs/app-integration.md`](docs/app-integration.md).

| Doc | What it covers |
|---|---|
| [`docs/flashing.md`](docs/flashing.md) | Flashing over USB, WiFi and from a phone; making a `.bin`; wireless diagnostics |
| [`docs/data-quality-audit.md`](docs/data-quality-audit.md) | What the recordings actually contain, and where they lie |
| [`docs/lean-investigation.md`](docs/lean-investigation.md) | Why the BNO055's fusion is not trusted for attitude |
| [`docs/direct-attitude-sensing.md`](docs/direct-attitude-sensing.md) | What a hardware answer to pitch/roll would cost |
| [`CLAUDE.md`](CLAUDE.md) | Handoff notes — conventions, verdicts, and what not to relitigate |

Replay tooling for `.trip` recordings is in [`tools/`](tools/): `triplib.py`
decodes the LZFSE container, `harness.py` re-runs an estimator over a recording
so a change can be scored against a ride instead of guessed at.

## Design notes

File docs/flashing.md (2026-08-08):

# Flashing a puck — USB and WiFi, complete reference

Verified working 2026-08-08 on the Light puck (macOS, arduino-cli, XIAO
ESP32S3). This is the single flashing document: networks, passwords, the
command lines for both paths, and the wireless diagnostics.

USB is needed exactly twice in a puck's life: the first flash of an
OTA-capable firmware, and recovery if an update ever bricks it. Everything
else is WiFi.

## Networks & passwords

The authoritative values are the `#define`s in the OTA block near the top of
each firmware file — if you change them there, update this table in the same
commit.

| | Light build (`tripper_light.ino`) | Full build (`tripper_puck.ino`) |
|---|---|---|
| WiFi network the puck raises (`OTA_AP_SSID`) | `Tripper-Light-OTA` | `Tripper-Puck-OTA` |
| WiFi password (`OTA_AP_PASS`) | `tripper-ota` | `tripper-ota` |
| Network-port name in Arduino IDE (`OTA_HOSTNAME`) | `tripper-light` | `tripper-puck` |
| Upload password (`OTA_PASSWORD`) | `tripper` | `tripper` |
| Puck's IP once joined | `192.168.4.1` | `192.168.4.1` |

Constraints when changing them: `OTA_AP_PASS` must be **at least 8
characters** (WPA2 rule — shorter and the AP silently fails to start), and
the SSIDs are deliberately different per build so two powered pucks never
raise the same network. These values are checked into the repo, so treat them
as labels, not secrets; the protection is that the mode is off unless toggled
on and never survives a power cycle.

## One-time setup

```bash
brew install arduino-cli
arduino-cli core install esp32:esp32
```

arduino-cli shares Arduino IDE's libraries folder (`~/Documents/Arduino`), so
the Adafruit/NimBLE libraries are already visible if the IDE ever built these
sketches. The first compile builds the whole ESP32 core and takes several
minutes **in silence** — it is not stuck; add `-v` to watch. Every compile
after that reuses the cache and takes seconds.

Both builds use the same FQBN, `esp32:esp32:XIAO_ESP32S3`, whose default
partition scheme already has the two app slots OTA needs. Paths below assume
the repo at `~/Documents/GitHub/Untitled`; swap `tripper_light` for
`tripper_puck` to flash a Full build.

## Flashing over USB

Find the port (the puck shows as "ESP32 Family Device" — generic USB
identity; the FQBN on the command line picks the real board):

```bash
arduino-cli board list
# -> /dev/cu.usbmodem101 (or similar)
```

Compile and upload in one step:

```bash
arduino-cli compile -u -p /dev/cu.usbmodem101 \
  --fqbn esp32:esp32:XIAO_ESP32S3 \
  ~/Documents/GitHub/Untitled/Tripper-DL1/hardware/firmware/tripper_light
```

Watch it boot:

```bash
arduino-cli monitor -p /dev/cu.usbmodem101 -c baudrate=115200
# Ctrl+C to exit
```

A healthy Light boot prints the LIGHT-build banner, `IMU ok | BMP280 ok`,
`CAN ok`, then a `[dbg]` line once per second. On v0x05 firmware, `gz` sits
within ~±0.2 deg/s at rest (window-averaged) and `baro` changes a little
every line (5 Hz readings).

## Flashing over WiFi

1. In the Tripper app: **Settings → Tripper Puck → WiFi flashing mode** on.
   The status line under the toggle confirms when the network is up.
2. On the Mac, join the puck's network from the WiFi menu (`Tripper-Light-OTA`,
   password `tripper-ota`). No internet while joined — irrelevant, nothing
   below needs it.
3. Compile, then upload to the puck's fixed address:

```bash
arduino-cli compile --fqbn esp32:esp32:XIAO_ESP32S3 \
  ~/Documents/GitHub/Untitled/Tripper-DL1/hardware/firmware/tripper_light

arduino-cli upload -p 192.168.4.1 \
  --fqbn esp32:esp32:XIAO_ESP32S3 \
  --upload-field password=tripper \
  ~/Documents/GitHub/Untitled/Tripper-DL1/hardware/firmware/tripper_light
```

`password=` is `OTA_PASSWORD`, not the WiFi password. `--upload-field` needs
a recent arduino-cli (`brew upgrade arduino-cli` if it complains).

**What success looks like, in order:** upload progress completes → the puck
reboots into the new image → the OTA network *vanishes* (the mode never
survives a reboot, by design) → the Mac drops back to its normal WiFi → the
app's toggle snaps off by itself and the puck is back on BLE within seconds.

## Making a `.bin`

Needed for the phone route below, and for handing a build to someone who has
no toolchain. `--output-dir` is the only difference from a normal compile:

```bash
arduino-cli compile --fqbn esp32:esp32:XIAO_ESP32S3 \
  --output-dir ~/Desktop/puck-bin \
  ~/Documents/GitHub/Untitled/Tripper-DL1/hardware/firmware/tripper_light
```

That directory then holds nine files and **only one of them is the firmware
you flash** (sizes from the 2026-08-08 Light build):

| File | ~size | What it is |
|---|---|---|
| **`tripper_light.ino.bin`** | **1.2 MB** | **The application image. This is the one.** |
| `tripper_light.ino.bootloader.bin` | 20 KB | Second-stage bootloader; written only on a first USB flash of a blank chip |
| `tripper_light.ino.partitions.bin` | 3 KB | Partition table; same — only on a blank chip |
| `tripper_light.ino.merged.bin` | 8 MB | All of the above glued into one whole-flash image, for factory programming |
| `*_flashed.bin` | — | Byte-identical copies arduino-cli leaves behind showing what it sent |
| `tripper_light.ino.elf` / `.map` | 19 MB each | Debug symbols. Not firmware. |

Two traps. `merged.bin` is the biggest file with the most reassuring name and
is **wrong** for OTA — it is a whole-flash image, not an app image. And an
app image starts with byte `0xE9` while `partitions.bin` starts `0xAA`, which
is the quickest way to tell you grabbed the wrong thing:

```bash
xxd -p -l1 ~/Desktop/puck-bin/tripper_light.ino.bin   # -> e9
```

Rule of thumb: the file ending in exactly `.ino.bin`, about 1.2 MB. Anything
8 MB is the wrong file. For reference the XIAO's default layout gives roughly
3.3 MB per app slot, so 1.2 MB leaves plenty of room.

## Flashing from a `.bin` — phone only, no laptop at the bike

The puck is bolted to the bike; this route needs nothing but the phone. It
works because the puck serves an ordinary HTML upload form at `/update` while
flashing mode is on — no arduino-cli, no espota, just a browser. (ArduinoOTA
speaks espota, which only the Arduino tooling implements, which is why the
laptop used to be mandatory.)

The last build is also checked in at **`releases/tripper_light.ino.bin`** in
the repo root, so you can grab it from GitHub on the phone directly and skip
the compile entirely. Rebuild it with the command above whenever the firmware
changes, and commit the new one in the same commit as the source.

AirDrop `tripper_light.ino.bin` to the phone once — it lands in Files — then:

1. Tripper app: **Settings → Tripper Puck → WiFi flashing mode** on.
2. Phone WiFi: join `Tripper-Light-OTA`, password `tripper-ota`.
3. Safari → `http://192.168.4.1/update`
4. **Choose File** → pick the `.bin` → **Upload**.

A percentage appears while it runs. Do not lock the phone, switch apps, or
reload the page mid-upload — a browser retry part-way through a write is how
a puck gets bricked. If the transfer does die, the firmware aborts the write
so the slot is clean; just start again. When it finishes the puck reboots
itself, the OTA network vanishes, and the app's toggle snaps off on its own.

The same endpoint works from the Mac when arduino-cli is not to hand:

```bash
curl -F "fw=@$HOME/Desktop/puck-bin/tripper_light.ino.bin" \
  http://192.168.4.1/update
```

Recovery is unchanged: USB always works and needs nothing from the running
firmware.

## Diagnostics over the same network

While the flashing network is up, the puck also serves what used to require
the USB cable:

```bash
curl http://192.168.4.1/        # one-page live status: build, uptime, reset
                                # reason, heap, cal, quatRejects, baro, CAN
curl http://192.168.4.1/log     # the last ~8 KB of debug lines, oldest first
curl http://192.168.4.1/update  # the upload form (open this one in a browser)
```

(Or open the same URLs in a browser.) The log ring lives in RAM **from
boot**, not from when the toggle went on — after something odd on the bench,
toggle WiFi flashing on and `/log` still holds the `[dbg]` lines from when it
happened. It opens with a `[boot]` line whose reset reason tells a power
cycle from a crash from an OTA reboot. The ring does not survive a power
cycle, and ride data is not here at all — rides live in the phone's `.trip`
files; the puck is deliberately stateless.

## Notes

- WiFi flashing mode is entered ONLY via the app's toggle (BLE control write
  `0x05` — the Light build has no buttons). Firmware never raises the radio
  on its own.
- The status packet's `otaState` byte carries the live state:
  `0` off · `1` network up, no client · `1+n` = n clients joined.

## If something goes wrong

- **Upload rejected / auth failed** — wrong `password=`; the *running*
  firmware does the checking, so use its `OTA_PASSWORD`.
- **No network appears after toggling** — the app's status line says what the
  puck reported; "no report" means firmware older than the feature (USB flash
  once). Also confirm the app shows Connected: the toggle is a BLE write.
- **Upload succeeds but the puck misbehaves** — flash back over USB; that
  path needs nothing from the firmware to work.
- **`arduino-cli` seems hung on compile** — first build of a core version;
  give it minutes, or re-run with `-v`.
- **`Can't open sketch: no such file or directory`** — the sketch path is a
  *folder* containing an `.ino` of the same name, and it is relative to where
  you are standing. From inside `tripper_light/`, the argument is `.`; from
  `hardware/firmware/`, it is `tripper_light`. The absolute path always works.
- **iOS says "no internet" and drops the OTA network** — the firmware answers
  Apple's captive-portal probe to prevent exactly this, so seeing it means
  firmware older than the `/update` feature. Tap "Use Without Internet" to
  finish this flash; the next build fixes it permanently.
- **Phone upload fails part-way** — nothing is half-written; the firmware
  aborts the slot on a broken transfer. Rejoin the network and start again.
  Do not reload the page while a percentage is still climbing.
- **Uploaded and the puck went quiet** — you probably sent `merged.bin`
  instead of `.ino.bin`. USB recovery, then re-read the table above.

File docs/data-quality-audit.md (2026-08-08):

# Data-quality audit — every channel, hunting instability

**Date:** 2026-08-08, against `Tripper_2026-08-08_15-55-02.trip` and
`Tripper_2026-08-08_16-30-22.trip` (v0x05 firmware, post-sign-fix app),
cross-checked where relevant against the four earlier rides of the same day.
Method: systematic sweep of timing, GPS, barometer, CAN, IMU, cross-channel
physics consistency, and session totals, per channel, with thresholds; every
flagged row inspected by hand before it was allowed to stand.

Findings ranked by how much they lie to the rider.

---

## 1. SERIOUS — the g-force channels are still built on the condemned fusion

`currentG`, `longitudinalG`, `lateralG`, `verticalG` (and the session `maxG`,
whose 100 Hz peak the firmware latches from the same source) are produced by
rotating the BNO055's **linear acceleration** by the BNO055's **quaternion** —
both outputs of the fusion that `lean-investigation.md` convicted. Lean and
slope were rebuilt from raw channels; the g-forces never were.

Measured consequences:

| check | expectation | observed |
|---|---|---|
| lateralG vs v·ψ̇/g, whole ride | strong correlation | **+0.01** (15-55), **−0.17** (16-30) |
| hardest braking rows, 15-55 | −0.66 g (from wheel dv/dt) | −0.14 g recorded |
| hardest braking rows, 16-30 | −0.24 g | **+0.32 g** — wrong sign |
| currentG parked, 15-55 | ~0 | +0.12 g phantom |
| corner magnitudes | — | plausible on one ride, ~2× high on the other — exactly the fusion's ride-to-ride mood |

**Fix (app):** derive the g-forces the same way lean was rescued — raw
accelerometer minus a gravity unit vector built from the estimator's own lean
and slope: `linear = rawAccel − ĝ(lean, slope)`; longitudinal = x, lateral =
−y (right-positive), vertical = z. At standstill this reads exactly zero by
construction. `maxG` needs a firmware follow-up eventually (the 100 Hz peak is
latched from fusion linear-accel on the puck — candidate for v0x06:
latch `max(|rawAccel| − 1g)` instead).

## 2. MODERATE — phone GPS fixes with 40–50 m accuracy are swallowed whole

Ride 16-30, t=198.4 s: a fix with `horizontalAccuracy` 47 m lands ~30 m
sideways from the track (implied speed 168 km/h against a wheel reading 64),
plus 9.7 m/s of fake GPS-altitude change. The rows before it carry hAcc 39–47;
once accuracy recovers to <16 the track snaps back. On the Light build these
phone fixes feed the odometer (`distanceMeters`), `gpsSlope`, and the
`wheelScale` learner (the learner's bounds and gain kept it safe — verified —
but the odometer and gpsSlope take the hit).

**Fix (app):** gate odometer accumulation and wheelScale lessons on
`horizontalAccuracy` ≲ 20 m; let the track renderer keep bad fixes if it wants
the continuity, but never let them teach anything.

Related, lower severity: phone-GPS droughts of 15–22 s appear once per ride
(t=85 on 15-55, t=180 on 16-30 — pocketed phone, hillside). During a drought
nothing learns and slope's distance axis rides on the wheel alone, which is
its designed degradation. The Full puck's own GNSS would remove this class
entirely; noted, not urgent.

## 3. MODERATE — single-row pressure burps at constant speed

Ride 15-55, t=67.4–67.8: mid-descent at a steady 41 km/h, the barometer blips
+0.6 m for two rows and back; recorded slope swings −10% → +2.6% → −12% inside
1.5 s. This is *not* the braking/acceleration transient (speed constant — the
aero gate correctly ignores it): it is a pressure gust — wind, a passing
vehicle, a wall. Seven such steps >3 m/s on 16-30, two on 15-55.

**Fix (app, cheap):** median-of-3 on the altitude samples entering the fit
window. Kills every single-row burp for 0.4 s of added latency, which the 1 s
display smoothing already dwarfs. The least-squares fit is otherwise defencelss
against a single wild point in a 10 m window.

## 4. INFORMATIONAL — measured constants worth knowing

- **Wheel over-read vs GPS ground: +13.6% / +14.8%** on the two rides —
  stable, consistent with the investigation's 13%; this is the tyre/gearing
  calibration `wheelScale` divides out. Its stability across rides is
  reassuring: the learner is converging on a real constant.
- **Phone-vs-puck barometer relative drift: ±5–8 m over a ride.** Two sensors,
  two enclosures, weather — expected; nothing uses them interchangeably.
- **Heart rate coverage 67% / 34% of rows** — the known watch under-sampling
  saga (see the iOS repo's CLAUDE.md); no new information, not a puck issue.
- **Timing:** row cadence clean (one 0.55 s hiccup in 4330 rows); GPS-era
  duplicates are by design (fix-scoped fields).
- **CAN:** no speed dropouts, no kickstand flicker, SOC monotone, cell spread
  sane, rpm/speed ratio steady outside genuine wheelspin. The bus tap is
  clean.
- **IMU:** no gyro spikes, no freefall/clipping accel rows, quatRejects flat
  (boot-time only), gyro calibration 3/3 throughout. The v0x05 window-mean
  telemetry is behaving.

## What was checked and found healthy (so it isn't re-checked)

Row timing and monotonicity; CAN internal consistency (P≈V·I, rpm/speed,
SOC, cells, kickstand); gyro/accel outliers; quatRejects trend; calibration
status; verticalG zero at rest; session-vs-integrated distance (ratio matches
the known wheel over-read); baro-vs-pressure channel agreement.

## Recommended order of work

1. Rebuild g-forces from raw accel + estimator attitude (fixes four channels
   and the g-g display; session maxG follows with a firmware v0x06).
2. hAcc gate on odometer + wheelScale learning.
3. Median-of-3 on the fit's altitude input.
4. Eventually: Full-build GNSS on the bike to retire phone-GPS droughts.

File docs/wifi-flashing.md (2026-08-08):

# Moved

Everything about flashing — networks, passwords, the arduino-cli commands for
USB and WiFi, the wireless diagnostics endpoints, and troubleshooting — now
lives in one place: [`flashing.md`](flashing.md).

This file briefly held the values table on its own, which meant the values
and the commands that use them were in different documents. One document is
better; this stub exists only so old links and habits don't dead-end.

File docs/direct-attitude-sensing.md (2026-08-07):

# Measuring lean and slope directly, instead of deriving them

**Status:** scoping note. Nothing here is built, and no code was changed to
write it. It exists to answer one question properly — *is there a part we can
buy or a method we can integrate that measures lean and slope, rather than
inferring them?* — because the honest answer is "yes for one of them, and yes
for the other but not the way you'd expect", and that deserves more than a
conversation.

Read [`lean-investigation.md`](lean-investigation.md) first. This picks up where
that leaves off: that document establishes the BNO055's fusion is wrong, this
one asks what a *correct* instrument would look like.

---

## The short version

| | Can it be measured directly? | With what | Realistic accuracy |
|---|---|---|---|
| **Slope** | Yes, today, cheaply | Barometer over ground distance | ~1.7° |
| **Slope** | Yes, much better | RTK GNSS | ~0.1° over 10 m |
| **Lean** | **Not by any single sensor** | — | — |
| **Lean** | Yes, with velocity aiding | GNSS velocity + gyro | ~1–2° |
| **Lean** | Yes, bought outright | GNSS/INS module | ~0.1–0.5° |

The interesting entry is the third row, and it is not a budget problem.

---

## Why no accelerometer reads lean, at any price

An accelerometer does not measure gravity. It measures **specific force** —
gravity and the vehicle's own acceleration, summed into a single vector with no
way to tell which part is which.

In a steady corner those two components add up along the bike's own vertical
axis. That is not a coincidence or an artefact; it is the definition of a
balanced corner. If the resultant force were *not* through the bike's centre
line, the bike would be falling over.

So an accelerometer strapped to a motorcycle reads "upright" at 45° of lean,
and it reads that correctly. The app's own estimator records the measurement:
lateral g averages **0.015** across these rides while moving.

This is why the answer to "can we buy a better sensor" is no. A navigation-grade
accelerometer costing more than the bike has the identical blind spot, because
the blind spot is in the physics of the quantity being measured, not in the
quality of the measurement.

It is also why the current firmware runs the BNO055 in IMUPLUS: no amount of
sensor fusion over accelerometer and gyro alone can recover what neither sensor
observes.

---

## The thing that breaks the tie

To separate gravity from acceleration you need **an independent measurement of
the vehicle's own acceleration**. Then:

```
gravity = specific force − acceleration
```

and roll falls straight out of where gravity points relative to the bike.

The standard source for that independent measurement is **GNSS velocity**. This
is the architecture behind every serious attitude system, from agricultural
autosteer to the aircraft the question invoked. The aircraft's advantage is not
that its gyros are better — though they are. It is that satellite navigation is
continuously telling its inertial system what it is really doing, so the
inertial system never has to guess whether a force is gravity or motion.

### Why velocity and not position

A GNSS receiver derives velocity from the **Doppler shift of the carrier**, not
by differencing positions. These are separate measurements with very different
error characteristics: position may be good to metres while velocity is good to
a few centimetres per second. A receiver with a mediocre position fix can still
have excellent velocity.

Differentiating that velocity gives acceleration in earth coordinates, accurate
enough to subtract from the accelerometer and leave gravity behind. u-blox
receivers report a live accuracy estimate (`sAcc`) alongside, so the filter can
weight it honestly rather than trusting it blindly.

---

## What is already on the bench

This is the part that changes the calculus, and it was a surprise.

The Full build carries a **u-blox NEO-8M**, already running at 5 Hz and 115200
baud. And the firmware already speaks UBX in both directions:

- [`sendUBX()`](../hardware/firmware/tripper_puck/tripper_puck.ino) builds UBX
  frames with correct Fletcher checksums — used today for `CFG-PRT`,
  `CFG-RATE` and `CFG-CFG`.
- [`waitAck()`](../hardware/firmware/tripper_puck/tripper_puck.ino) is already a
  byte-level UBX receive state machine. It only recognises `ACK-ACK` today, but
  it is the same skeleton any UBX message parser needs: sync bytes, class, id,
  length, payload, checksum.

What is missing is narrow: **the receiver is configured over UBX but read over
NMEA.** `TinyGPSPlus` parses NMEA sentences, and NMEA carries 2D speed and
course — the 3D velocity vector never reaches the firmware, because the
sentence format has nowhere to put it.

`UBX-NAV-PVT` carries `velN`, `velE`, `velD` in mm/s plus `sAcc`, in one
message, at whatever rate the receiver is configured for.

**So on the Full build, the hardware for velocity-aided attitude is already
fitted and already talking the right protocol.** The gap is a message parser and
a filter, not a bill of materials.

The Light build has no receiver on the puck at all — position comes from the
phone at 1 Hz, already smoothed by CoreLocation. That is far too slow and too
filtered to observe corner dynamics, so velocity aiding would be a Full-build
capability unless the Light puck gained a receiver of its own.

---

## The routes, by effort

### 1. Velocity-aided attitude on the hardware we already have

Configure `UBX-NAV-PVT`, parse it, and run an error-state Kalman filter: the
gyro propagates attitude between fixes, and the GNSS velocity derivative
corrects the accumulated error and pins down which way gravity actually points.

- **Parts cost:** nothing. It is already on the bike.
- **Accuracy:** roughly 1–2° of roll, including the components the kinematic
  formula structurally cannot see.
- **Effort:** substantial, and this is the honest catch. A correct 15-state
  error-state filter with proper lever-arm handling and covariance tuning is
  not a weekend, and a badly tuned one is worse than the formula it replaces
  because it fails in ways that look plausible.
- **Rate:** the NEO-8M will do 10 Hz on a single constellation. At 5 Hz across
  multiple constellations the corner dynamics are marginal but usable.

### 2. Buy a module that has already done the work

GNSS/INS units — SBG Ellipse, VectorNav VN-200, Inertial Labs, Advanced
Navigation Spatial — contain the IMU, the receiver and the filter, and output
roll, pitch and heading already fused over serial.

- **Accuracy:** typically quoted 0.1–0.5° roll/pitch.
- **Effort:** read a serial protocol. No filter to write or tune.
- **Cost:** roughly $1k–4k depending on grade — worth checking current pricing,
  this moves.
- **Cost in other ways:** physically larger than the whole current puck, more
  power, its own antenna siting requirements.

This is what professional data loggers use, and it is the honest answer to
"can I just buy the thing".

### 3. RTK, for slope specifically

A ZED-F9P-class receiver with a correction stream gives centimetre-level
altitude. Over the 10 m window the app now fits slope across, that is roughly
**0.1°** — against the barometer's ~1.7°.

- Turkey has a national CORS network (**TUSAGA-Aktif**) that serves corrections
  over NTRIP; the phone already carries the mobile data to fetch them.
- It would improve the *distance* axis too — the quantity that turned out to be
  wrong when the wheel was measuring it.
- Needs sky view and a decent antenna, and corrections mean a live data link.

### 4. Dual-antenna GNSS

Two antennas on a fixed baseline give true heading and pitch from the carrier
phase difference, with no inertial sensor involved at all.

For **roll** you need lateral separation, and a motorcycle offers maybe 50–60 cm.
At ~1 cm baseline accuracy that is about 1° — real, but marginal, and it means
two rigidly mounted antennas that must not move relative to each other on a
vehicle designed to flex. Mechanically the least attractive option here.

---

## What will not work, and why

**A magnetometer.** In theory this is the clean answer: Earth's magnetic field
is a second reference direction, independent of gravity, and two non-parallel
reference vectors fully determine attitude. That is what 9-axis chips are for.

On this bike it is hopeless. The climb analysed in the trip data drew a measured
**105 A peak** through the motor cabling. The field from currents at that scale
swamps Earth's field entirely, and it varies with throttle — so the error would
be largest exactly when on the gas, which is exactly when the reading matters.
No calibration fixes a disturbance that changes with the throttle. The BNO055
already runs in IMUPLUS with the magnetometer disabled for this reason.

**A better accelerometer.** Covered above: the blind spot is in the quantity,
not the instrument.

**A better gyro.** The gyro's weakness is drift, not blindness, and drift is
already handled by referencing the kinematic term through a complementary
filter. A better gyro lengthens the interval over which integration can be
trusted; it does not tell you where gravity is.

---

## What each option actually buys

| | Lean accuracy | Sees rider lean-off | Sees camber | Slope | Parts |
|---|---|---|---|---|---|
| **Today** (gyro + wheel speed + baro) | good through corners | no | no | ~1.7° | fitted |
| **Velocity-aided** (existing NEO-8M) | ~1–2° | **yes** | **yes** | ~1.7° | fitted |
| **GNSS/INS module** | ~0.1–0.5° | yes | yes | ~1.7° | $1k–4k |
| **+ RTK** | as above | — | — | **~0.1°** | ~$300+ |

The honest note on the first row: `tan(lean) = v·ψ̇/g` is not a poor substitute
for a real measurement — it is what most professional motorcycle telemetry
quotes, including the lean angle behind cornering ABS. Bosch's system is a
6-axis IMU plus a vehicle model plus wheel speeds. Same physics, more modelling.

What the formula structurally cannot see is **the rider moving on the bike** and
**road camber**, because it describes the bike's balance rather than its
geometry. That gap is what velocity aiding closes, and it is the only thing it
closes.

---

## Recommendation for this bike

The riding this puck is built for is **technical climbing at low speed**, and
that reshapes the priorities:

- **Lean matters least there.** At 3 km/h in a rut there is barely a turn rate
  to derive lean from, and not much lean to measure. The kinematic term is
  weakest exactly where the riding is slowest — but so is the demand for it.
- **Slope is where the money pays.** Grade is the number that describes a
  technical climb, and it is currently good to ~1.7° with scatter from a
  barometer. RTK would take it to a tenth of a degree on every pitch, and would
  sharpen the ground-distance measurement at the same time.

So if one upgrade is bought, buy the one for slope. Velocity-aided lean is the
intellectually correct fix and the one that closes a real gap in what the
current method can observe — but for this riding it buys the least.

---

## If it were pursued, what else would move

Noted here so the scoping is honest, not as a plan:

- **The telemetry packet has room.** It is 78 bytes today against a negotiated
  ATT MTU of 247, so a 3D velocity vector and its accuracy estimate fit without
  restructuring. The `ver` byte already gates parsing, and the app's
  `>=`-based parse gates mean an older app reads a newer packet and drops the
  tail silently — which Settings now warns about.
- **`speed_cmps` and `course_cdeg` become redundant.** Both are 2D projections
  of the velocity vector that would replace them.
- **The Light/Full split widens.** Today the two builds differ in what they
  report but not in how good it is. Velocity aiding would make the Full build
  measurably more accurate rather than merely better equipped, which is a
  product decision as much as a technical one.
- **Nothing here helps the recorded rides.** As with the slope fix, only rides
  recorded afterwards would carry it.

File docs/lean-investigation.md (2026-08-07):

# Lean and slope: what is wrong, what has been ruled out, what to check next

**Status:** open. Three rides investigated, five hypotheses eliminated, the
cause not yet identified. Firmware v0x04 exists to make the next ride
diagnosable.

Read this before touching attitude code. It exists so the next person — most
likely us in three weeks — does not re-run experiments that have already been
run, and does not re-adopt an explanation that has already been disproved.

Two companion documents:
[`direct-attitude-sensing.md`](direct-attitude-sensing.md) asks what a correct
instrument would look like, rather than what is wrong with this one — it is
where the "can we just buy a sensor" question is answered properly, and it
qualifies the claim below that no sensor fixes lean. The **2026-08-02** ride
added here corrected a recommendation this document previously made about
slope; see "Slope's distance" below.

---

## The symptom

Lean is unusable, and slope is worse than it looks. From
`Tripper_2026-08-03_16-10-18.trip` (401 s, 2.9 km, max 95 km/h, puck IMU and
CAN at 5 Hz, GPS at 1 Hz):

| | 2026-07-31 ride (pre-fix) | 2026-08-03 ride (post-fix) |
|---|---|---|
| straight-line mean lean | −1 … −30° wandering | −4.4° (sd 4.1) |
| straight riding reading \|lean\| > 10° | 48% | 9.0% (>5°: 45%) |
| correlation vs `atan(v·ω/g)` | −0.52 | −0.20 |
| corners with the correct sign | 0/14 | 2/14 |

Commit 7ac31e7 (body-side `qRef`, tilt-only reference) is a genuine fix and its
reasoning still holds — it is simply not what is producing the readings above.

Two windows worth keeping as regression cases, both spotted by eye during
playback and both confirmed in the data:

- **t = 230–239 s, dead straight** (course 340–359°, 30–50 km/h). Reported lean
  sits at −8 to −12° for ten continuous seconds. The puck's own gyro says the
  bike is not rolling during that time.
- **t = 353–365 s, descending.** Reported slope +1.3°. Puck barometer −1.5°,
  phone barometer −2.9°, GPS altitude −6.0 m over 92 m. Three independent
  witnesses against one.

Over the whole ride, slope is off by −3.1° on average with ±5.2° of scatter
against the barometric road grade. Its +0.41 correlation looks respectable and
hides exactly this.

### A third case, and the sharpest one: 2026-08-02, t = 3088–3099 s

`Tripper_2026-08-02_14-43-58.trip`, an eleven-second technical climb. The rider
later returned to the hill and measured it with an inclinometer: **33–40° at
mid-to-top**. Ground truth from GPS ground track and the puck barometer is
**24.1° averaged over the 9.6 m steep pitch**, and **+1.6°** across the 23 m
flat approach to it.

What the fusion reported against that:

| | true | reported | error |
|---|---|---|---|
| flat approach | +1.6° | ~+35° | **+33°** |
| the steep pitch | +29…+33° | +62…+68° | **+33°** |
| 9 s later, t = 3102 | +0.4° | +31.5° | +31° |
| 15 s later, t = 3108 | ~0° | +2.0° | ~0° |

**The error is a near-constant +33° bias that survives a 30° change in the real
slope, and then decays to nothing over about six seconds.** Two things follow,
and both sharpen conclusions this document already reached from weaker evidence:

- The fusion's *response* to real attitude change is roughly correct — the
  reported value tracks the hill going up and coming down. It is the **zero**
  that is wrong. This is the same finding as "the changes in attitude are right;
  the absolute angle is not", but here it is visible against a 30° swing rather
  than inferred from a correlation.
- The bias **decays on its own**, which no static mount or axis error can do,
  and which the standstill tests could never have caught because they only ever
  sampled the settled state. It reads like the fusion's gravity correction
  slowly re-converging after being knocked off.

Worth keeping as the primary regression case: it has an independently measured
answer, the error is an order of magnitude larger than the 3:50 window, and the
barometer is unusually well behaved across it (a clean, monotonic +5.83 m).

## Ruled out — do not revisit without new evidence

| Hypothesis | How it was tested | Result |
|---|---|---|
| Mount, axes or zero wrong | Roll and pitch at all six standstills in the ride | Return to ≈0 every time (−2.6…+0.9°). A static error would be present at rest too |
| Gyro drift | Signed gyro mean at each standstill | ≤0.13 deg/s. Would take minutes to build 10°, and the errors come and go rather than accumulate |
| Frame algebra still wrong (residual mount yaw) | Regressed attitude-implied body rates onto the raw gyro | M ≈ diag(0.81, 0.18, 0.94), off-diagonals small — the body-side `qRef` is doing what it claims |
| The bike's own acceleration read as tilt | Subtracted `atan(a/g)` using CAN dv/dt from reported slope | Made it **worse**: correlation 0.41 → 0.25, sd 5.21 → 7.54 |
| Vibration level | Correlated \|roll\| against local gyro spread and accel shake on straight rows | +0.13 / +0.30, and the worst window (3:50) has *below*-average vibration |
| Puck not rigidly on the bike | `puckGyroZ` vs GPS course rate; `puckGyroX` at corner entries | Z is up, X is forward, gyro sees every corner. Hardware and mounting are sound |

Two explanations were offered to the rider and then withdrawn, both recorded
here so they are not re-proposed: *coordinated-turn geometry* (true, but cannot
produce a wrong reading on a straight road, so it does not explain 3:50), and
*acceleration mistaken for tilt* (tested and refuted, row 4 above).

## Established as healthy

- **The gyro.** Bias ≤0.13 deg/s at rest, correct turn direction, and it
  matches the attitude's own rate of change at r = +0.87. The *changes* in
  attitude are right; the absolute angle is not.
- **The mount, the axes and the mount zero**, per the table above.
- **The barometer.** Grade from puck baro over distance travelled tracks GPS
  slope at +0.75 and needs no attitude at all.

## The ceiling on lean, independent of this bug

In a steady corner the force a leaned bike feels runs straight through the
bike — that is what stops it falling over. Measured on this ride: lateral g
averages +0.015 (sd 0.12) while moving above 20 km/h, above 0.2 g on only 10%
of rows. **Any device that infers tilt by feeling gravity therefore reads
"upright" mid-corner**, from a $5 accelerometer to a dedicated inclinometer.

So lean must ultimately come from `atan(v·ψ̇/g)` — CAN speed and the gyro's
vertical-axis rate — with the gyro filling in the transitions. Validated
offline against this recording at 5 Hz (the firmware would run 100 Hz), τ = 1–2 s:

| | as shipped | gyro + kinematic reference |
|---|---|---|
| corner sign agreement | 2/14 | 10/12 |
| straight-line mean | −4.4° (sd 4.1) | −0.14° (sd 2.9) |
| max lean | — | 23° (plausible) |

This is necessary but **not sufficient**: it does not explain or fix the 3:50
straight-line window.

## What v0x04 adds, and why

Everything in the packet that bears on attitude — quaternion, linear accel,
even the calibration byte — is a *product* of the BNO055's fusion. They
corroborate each other by construction, whatever the fusion decides. That is
why the investigation ran out of evidence: every remaining witness was the
accused.

v0x04 (86 bytes) appends the **raw accelerometer** (offset 78, sensor frame,
gravity included, sampled in the same 10 ms tick as the quaternion) and
**`quatRejects`** (offset 84). See the packet table in `README.md`.

## What to check when the next ride lands

1. **`acc` direction vs reported attitude, across t = 230–239 s equivalent** —
   a straight, steady stretch. Low-pass `acc` over ~2 s and compare its
   direction with the roll/pitch the quaternion reports.
   - Raw accel points true down, quaternion says −10° → **the fusion is at
     fault.** Stop using its attitude; run our own filter on raw accel + gyro,
     or move to a BNO085/BNO086.
   - Raw accel is itself tilted while the bike is provably straight → **the
     accelerometer is being fed a tilted "down"** — mount flex, resonance or
     rectified vibration. A new chip would read the same nonsense; fix the
     mechanics.
2. **`acc − lin`** — the fusion's own gravity vector. If it disagrees with the
   quaternion's down, the fusion is internally inconsistent, which is
   conclusive on its own.
3. **`quatRejects`** — flat is healthy. Climbing mid-ride means the attitude is
   being *held* across glitched I2C reads rather than tracking the bike.

### Bench test that needs no ride

Bike upright on the stand, puck powered, motor running so it vibrates. Watch
reported lean for a minute. If it wanders more than a degree while the bike is
provably upright, the fusion (or the mount) is confirmed at fault and no
algorithm layered on its output will save it. Then have someone push the bike
in a straight line and watch again.

## Sensor replacement — only after step 1 answers

- **Slope:** buy nothing. The BMP280 already on the puck beats the IMU's pitch
  today. Altitude over distance needs no attitude, so it cannot be corrupted by
  any of this. **See "Slope's distance" below — the second half of this
  recommendation was wrong.**
- **Lean:** no sensor fixes it *on its own* — see "the ceiling" above, which
  still holds for anything that infers tilt from gravity. It is not the whole
  story: a second, independent measurement of the bike's own acceleration makes
  lean observable again, because gravity can then be recovered by subtraction.
  GNSS velocity is that measurement, and the Full build's NEO-8M already
  reports it in a message the firmware does not currently read. See
  [`direct-attitude-sensing.md`](direct-attitude-sensing.md). The BNO055's gyro
  remains good enough either way.
- **If replacing anyway:** BNO085/BNO086 is the sensible successor — same I2C,
  same 3.3 V, Adafruit breakout, far less opaque fusion, exposes raw sensors
  properly. Not a drop-in code swap: different library (SH-2), about a day.

## Slope's distance: a correction to this document

This document previously recommended the barometer **plus CAN speed** for
slope. The barometer half is right. The CAN-speed half was wrong, and the
2026-08-02 ride is what disproved it.

A driven wheel measures its own rotation, not the bike's progress. Comparing
wheel-integrated distance against GPS ground track on that ride:

| segment | wheel | GPS | ratio | mean power |
|---|---|---|---|---|
| cruise before | 137.0 m | 113.8 m | 1.20× | 746 W |
| **the climb** | **68.5 m** | **27.2 m** | **2.52×** | **3332 W** |
| after | 89.6 m | 85.0 m | 1.05× | 372 W |
| whole ride | 14 306 m | 12 655 m | 1.13× | 520 W |

GPS horizontal accuracy is a flat 4.7 m across all of them, so this is not the
fix degrading; and a stationary minute afterwards gives a free noise floor of
3.5 m per 60 s, well under a metre across an eleven-second window. The wheel was
turning 2.5× further than the bike travelled, at 60% slip, under 105 A.

Dividing a real rise by that inflated run reports a gentler hill than the one
ridden, **and it goes most wrong exactly where slope is worth reading.** Slope's
run must come from GPS; the wheel is fit only to dead-reckon between fixes.

Two further numbers worth keeping, both measured on this ride:

- **Barometer short-term noise is 0.111 m** (1σ, sample-to-sample while parked).
  The figure over a whole stationary stretch is 0.44 m, but that includes
  weather drift, which a rolling window cancels. Use 0.111 m when sizing a
  window; the larger number will talk you out of short windows for no reason.
- **The fit window is a decision, not a limit.** Fitting grade over 40 m of road
  — a road-gradient length — reported the 24.1° pitch above as 13.5°, because
  the pitch is 9.6 m long and the rest of the window is flat. Against the known
  answer: 10 m → 24.3°, 15 m → 22.9°, 40 m → 13.5°, while scatter on flat ground
  moves only 1.03° → 1.71°. For technical climbing the window must be sized to
  the climbs, not to roads.

## Reproducing the analysis

`.trip` files are `"TRIP"` + a version byte + an LZFSE-compressed JSON payload
of `{session, samples}`. On macOS, `compression_decode_buffer` from
`/usr/lib/libcompression.dylib` with `COMPRESSION_LZFSE = 0x801` decompresses
the body; no third-party library needed. The fields used above are
`rollDegrees`, `pitchDegrees`, `imuSlopeDegrees`, `puckGyro{X,Y,Z}`,
`canSpeedKmh`, `puckBaroAltitudeMeters`, `latitude`/`longitude` and
`lateralG`.

Course and turn rate should be derived from GPS **positions**, not from
`headingDegrees` — the two agree here (median offset −0.3°) but the position
track is the one that can be trusted at low speed. Sanity-check any GPS
reference against CAN speed first: on this ride they correlate at +0.95.

**Do not use `canSpeedKmh` to build a distance axis** — see "Slope's distance".
The +0.95 correlation above is real and still worth using as a sanity check, but
correlation is not scale: the wheel tracks the shape of the speed trace while
over-reading its magnitude, by 13% in normal riding and 152% under wheelspin.
Use `distanceMeters` (the app's GPS odometer, written on GPS rows only, so
interpolate between them) or haversine over `latitude`/`longitude`.

`distanceMeters` is roughly 20% populated in puck-era files and 100% in the
phone-only ones, because it is written when a fix lands rather than on every
row. That is a sampling difference, not missing data.

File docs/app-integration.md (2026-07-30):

# Tripper app — puck integration notes

Changes the [Tripper iOS app](https://github.com/kbirand/Tripper) needs in order
to talk to the puck correctly. Written after the Light/Full build split and the
regen-level decode landed.

Byte layouts are authoritative in [`README.md`](../README.md) → BLE protocol;
this document covers only what the **app** has to do differently, and why.

## Packet reference

**Status packet — 14 bytes, notified at 1 Hz**, little-endian:

| Offset | Type | Field |
|---|---|---|
| 0 | u8 | `ver` (0x01) |
| 1 | u8 | `fix` |
| 2 | u8 | `sats` |
| 3 | u8 | **`battPct`** — see §1 |
| 4–5 | u16 | `hdop_c` |
| 6–9 | u32 | `uptime_s` |
| 10–11 | i16 | `temp_x10` |
| 12 | u8 | `marker` |
| 13 | u8 | **`caps`** — see §3, was `reserved` |

**Telemetry packet — 70 bytes at 5 Hz.** The byte this document cares about is
**offset 50, `canFlags`**.

---

## 1 · `battPct` is a constant, not a measurement

The app renders `battPct == 0xFF` as `USB` in the settings list. The puck **has
no battery** — that was decided when it moved to bike power (no LiPo, no charge
circuit, no fuel gauge) — so both firmwares assign the byte unconditionally:

```c
s.battPct = 0xFF;   // tripper_puck.ino  and  tripper_light.ino
```

No code path writes anything else, on either build, on any power source.

**Why it misleads rather than merely being useless.** In production the puck runs
off the **5 V BEC from the bike's traction pack**. USB-C is only connected for
flashing, and never at the same time as the BEC — so `USB`, the single state the
row can display, is the one state that should never be true while riding.

**Fix, preferred:** delete the row. It cannot carry information.

**Fix, if a power row is wanted:** label it from the sentinel's *meaning*, not
its value.

```swift
// battPct is a sentinel, not a measurement.
// 0xFF = externally powered (BEC in production, USB while flashing).
let powerLabel = status.battPct == 0xFF ? "External" : "\(status.battPct)%"
```

Keep the `!= 0xFF` branch only as future-proofing should a battery ever appear.

---

## 2 · Regen level — decoded, shipping, not yet displayed

Regen rides in **`canFlags`** at telemetry **offset 50**:

| Bits | Field |
|---|---|
| 0 | CAN live |
| 1 | kickstand down |
| 3:2 | ride mode — 1 Eco, 2 Sport |
| **6:4** | **regen level, 1–4** |

```swift
let canFlags = telemetry[50]
let canLive  = canFlags & 0x01 != 0
let regen    = Int((canFlags >> 4) & 0x07)   // 1...4, 0 = unknown
```

Behaviour verified on the bench across two independent captures and 10 button
presses, including a descending sweep:

- Values are **only ever 1–4**.
- The selector **reverses at each end** instead of wrapping — 4→3→2→1→2→3→4 —
  so it never rolls `4→1`, and **`0` never appears on a live bus**.
- Therefore `regen == 0` unambiguously means *not known yet* and is safe to
  render as `—`.

Worth recording into the ride log, not just showing live: regen level changes
how the bike decelerates, which is real context when replaying a ride corner by
corner.

### Gate every CAN field on `canLive`

This applies to the rows that already exist (`Bike battery`, `Ride mode`,
`Kickstand`) as much as to regen. The firmware **zeroes the whole CAN block**
whenever no frame has arrived in the last 2 s, so an ungated read of a sleeping
bike shows 0 % battery and Eco mode rather than showing nothing:

```swift
guard canLive else { /* render "—", or hide the bike section */ }
```

A parked bike and a disconnected transceiver are indistinguishable by design —
`canFlags` bit 0 is the only thing that separates "real zero" from "no data".

---

## 3 · A Light puck has no GPS — read `caps` first

There are now two hardware builds. The **Light build has no GPS at all** and the
phone must remain the position source. But a Light puck currently looks
identical to a Full puck that hasn't got a fix — both report `flags` bits 0–1
clear, `lat/lon/alt = 0`, `sats = 0`, `hdop = 9999`, `gpsTimeMs = 0xFFFFFFFF`.

That sameness is deliberate: it is why no app branch is needed to *parse* either
build. But it means `GPS: no fix` reads as a fault when it is a permanent
property of the hardware — and the current settings copy promises something a
Light puck cannot do:

> *"While it's live, its 5 Hz GPS and bike-mounted motion sensor are recorded
> instead of the phone's"*

If the app ever stops recording phone GPS on the strength of that promise, a
Light build logs **no position at all**.

### Capability bits — status byte 13

| Bit | Meaning | Light | Full |
|---|---|---|---|
| `0x01` | has GPS | — | ✅ |
| `0x02` | has OLED | — | ✅ |
| `0x04` | has buttons | — | ✅ |
| `0x08` | has CAN | ✅ | ✅ |

Light sends `0x08`; Full sends `0x0F`.

```swift
struct PuckCaps {
    let raw: UInt8
    var hasGPS:     Bool { raw & 0x01 != 0 }
    var hasOLED:    Bool { raw & 0x02 != 0 }
    var hasButtons: Bool { raw & 0x04 != 0 }
    var hasCAN:     Bool { raw & 0x08 != 0 }

    // IMPORTANT: 0 means firmware older than this field, NOT "no capabilities".
    // Every firmware predating it was the Full build, so treat 0 as Full.
    static func parse(_ b: UInt8) -> PuckCaps { PuckCaps(raw: b == 0 ? 0x0F : b) }
}
```

### What to change

1. **Position source** — when `!caps.hasGPS`, keep recording phone GPS and never
   hand over. This is the one that risks losing ride data.
2. **GPS row** — show `Not fitted` instead of `no fix`, or hide the row.
3. **Settings copy** — vary it per build, e.g. *"Its bike-mounted motion sensor
   and the bike's own CAN data are recorded; position comes from your phone."*
4. **`Identify puck`** — `caps.hasOLED` is false on Light, so nothing visibly
   happens. Hide the button, or say it has no indicator on this build.

---

## 4 · Marker semantics differ between builds

Control opcode `0x01` is **not** symmetric:

| Build | Meaning of `0x01` |
|---|---|
| Full | An **ack** — the D2 button already counted the marker; this flashes MARK on the OLED |
| Light | **Originates** the marker and increments the counter — there is no button |

If the app suppresses `0x01` believing it to be cosmetic, markers become
impossible on a Light puck. Send it unconditionally; both builds accept all four
opcodes, so the app never has to withhold a control write.

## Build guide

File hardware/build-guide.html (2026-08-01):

Tripper Hardware · e-bike edition

# Tripper Puck

A matchbox-sized GPS + IMU + barometer telemetry puck that streams to the Tripper app over BLE and reads the bike's own CAN bus. Powered from the bike through a 5 V BEC — no battery, no SD card. Headless by design: the phone is its recorder, the OLED is a convenience.

Budget ≈ ₺3.700 core Size rear ≈ 55 × 40 × 22 mm + bar box Power bike 5 V BEC Build time 1 weekend

## The concept

Why this stays small: the entire physical interface is four things.

Power

5 V BEC

Steps the bike's pack to 5 V → VUSB · no battery, boots with the bike

Recorder

The phone

BLE telemetry into the Tripper app · no SD card

Buttons

Two

D1 steps screens · D2 marks / zeroes attitude

Status

OLED

0.91" screen — clock / data / bike-CAN + all status

Everything else — live dashboard, reviewing rides, naming, exporting — already exists in the Tripper app.

Scope pivot — e-bike edition (2026-07-21, CAN added 2026-07-23) The puck targets the e-bike: powered from the bike through a 5 V BEC (no LiPo, no slide switch) and BLE-first with no microSD — the phone records through the Tripper app's recorder pipeline, so the old v2 BLE link is the product. Consequences: LiPo + SD module + slide switch + NeoPixel are gone, the auto-record state machine moves into the app, and the puck becomes a stateless sensor that boots with the bike. It gained a second input path: a listen-only SN65HVD230 CAN transceiver on D8/D9 reads the bike's own bus (battery %, pack voltage, cell balance, motor current, kickstand, ride mode, regen level) straight into the telemetry packet. Status lives entirely on the 0.91" OLED; the two buttons are D1 (screens) and D2 (marker / mount-zero). Trade-off accepted with open eyes: no BLE link = no data for that stretch — the SD "black box" is gone; re-add it later if a lost ride ever hurts. Verify the BEC holds 5 V at standstill and doesn't drop out at low load.

Design rule Resist adding screens, menus, or more buttons. Every feature that needs a UI belongs in the phone app, where it's already built and glove-tested.

## Choosing a build

Two configurations share one codebase and one BLE contract. Pick before you order — the Light build is four parts and one enclosure.

| Light build | Full build
Physical form | one box at the rear | rear box + handlebar module
Sensing | IMU, barometer, bike CAN | IMU, barometer, bike CAN, GPS
Display | none — the app is the UI | 0.91" OLED, 4 screens
Buttons | none — the app sends control writes | two (screens · marker/zero)
Position from | the phone's GPS | the puck's own 5 Hz GPS
Firmware | firmware/tripper_light/ | firmware/tripper_puck/
Parts | 4 | 8
Wires to run | 6 | 14
Enclosures | 1 | 2

Start with the Light build It is the entire telemetry product — fused orientation, g-force, barometric altitude and every decoded bike-CAN signal — in four parts, and your phone already carries a GPS the app already reads. The Full build buys 5 Hz position (the phone's is 1 Hz), a dashboard readable with the phone pocketed, and two hardware buttons.

The Full build is strictly additive. The handlebar parts land on pins the Light build leaves free (D1, D2, D6, D7), so getting there is an upgrade rather than a rebuild — nothing already soldered gets moved. The BLE packets are byte-identical across both, so the app needs no branch: a Light puck reports its GPS block as invalid, the same state a Full puck reports before it gets a fix, and a capability byte in the status packet says which is on the other end.

## Shopping list — Turkey

Prices and stock verified on-site 2026-07-11. Everything below is orderable domestically — no customs. The first block is the Light build; the second is what Full adds.

Buy direct from Robotistan — not Hepsiburada The same Robotistan-sold 10DOF board lists at ₺1.906,27 on Hepsiburada and ₺1.530,69 on robotistan.com. Identical seller, identical box, ₺375 marketplace tax. Check the shop's own site before every order.

| Part | Role | Source | ≈ Price
① Light build — the puck · everything below is required
Obtained | Seeed XIAO ESP32-S3SAMM order SM83985 · 2026-07-10 | Brain · BLE 5.0 · on-chip TWAI CAN controller | SAMM (https://market.samm.com/en/seeed-studio-xiao-esp32s3-en) | ₺400–600
Obtained | Gravity 10DOF AHRS BNO055 + BMP280Robotistan · 2026-07-11 | On-chip sensor fusion — quaternions, linear accel & gravity vector straight off the chip + barometer. No fusion code to write. | Robotistan (https://www.robotistan.com/gravity-bno055-bmp280-akilli-10dof-oryantasyon-sensoru-ahrs) | ₺1.531
Obtained | SN65HVD230 CAN moduleAlkatronik / Hepsiburada · 2026-07-23 | Reads the bike's own CAN bus — 3.3 V transceiver, no level shifting. The ESP32-S3's built-in TWAI controller is the CAN peripheral; this is only the physical layer. | Hepsiburada (https://www.hepsiburada.com/alkatronik-sn65hvd230-can-modulu-p-HBCV00000FDLXI) | ₺60–120
Obtained | 5 V BEC, 3 A (DC-DC step-down)2026-07-23 | Steps the bike's traction pack down to a clean 5 V and feeds the XIAO's VUSB pin. Sized well above the ~150 mA the puck draws. | any hobby / RC shop | ₺100–200
② Full build adds — the handlebar module · skip all of this for a Light build
Obtained | u-blox NEO-8M GPS (GYGPSV1, patch antenna)Robotistan · 2026-07-10 | Position · configure 5 Hz via UBX (10 Hz single-constellation). The Light build uses the phone's GPS instead | Robotistan (https://www.robotistan.com/ublox-gygpsv1-gps-modulu) | ₺400–800
Obtained | SSD1306 0.91" OLED 128×32bench extra, promoted 2026-07-21 | Clock / live-data / bike-CAN screens and every status indicator. Joins the existing I²C bus at 0x3C — no extra pins | any hobby shop | ₺60–120
Obtained | Buttons: 12 mm glove button + HW-4832026-07-11 | D1 = screens · D2 = marker / mount-zero (no slide switch, no status LED) | any hobby shop | ₺30–60
③ Both builds
Obtained | Consumables: silicone wire 28 AWG, heat-shrink, JST leads, 2 mm foam pad2026-07-11 | Wiring + vibration isolation | any hobby shop | ₺100–150
Core | M8 4-pin connector pair 219A-04MSR panel + ASM08AF04001 cable | Bike → rear enclosure: +5 V, GND, CAN_H, CAN_L. Male on the panel, female on the live cable side. Pulling it isolates power and CAN before you flash. | local connector stockist | ₺525
Core | M12 8-pin A-coded pair + shielded 8-core cable | Rear → handlebar enclosure: 3V3, GND, SDA, SCL, GPS TX/RX, two buttons. M12 over M8 8-pin — bigger contacts, field-assemblable, far easier to terminate. | local connector stockist | ₺400–700
Core | Handlebar-run passives: 2× 2.2 kΩ (or 1.5 kΩ past 2 m), 2× 10 kΩ, 2× 100 nF, 1× 100 µF | I²C pull-ups, button pull-up/filter networks, and the bulk cap at the bar end. Without these a metre of cable gives you phantom presses and a torn display. | any electronics shop | ₺30
Light build total (① + ③) | | | | ≈ ₺2.200–2.500
Full build total (① + ② + ③, two enclosures) | | | | ≈ ₺3.500–4.700

✅ BOM complete (2026-07-11) · go/no-go gate PASSED (2026-07-21) Every core part is in hand, and the one test that could sink the build is done: both chips answered at 100 kHz (0x28/0x76, correct chip IDs), then 59,722 continuous quaternion reads over 10 minutes in IMUPLUS mode with zero errors (worst-case transaction 2.58 ms). The ESP32 clock-stretch risk is retired at 100 kHz — the Gravity board is a keeper and the return window no longer matters. Test sketch: hardware/firmware/i2c_gate/.

Decision record — why not the ₺337 GY-87 The original baseline was a GY-87 (MPU-6050 + HMC5883L + BMP180, ₺336,98 (https://www.robotistan.com/mpu6050-hmc5883l-bmp180-10dof-sensor-karti)) — 6-axis, DMP quaternions, drifting yaw — on the theory you'd swap in a BNO085 later. That upgrade path doesn't exist in Turkey (see below), which turned the cheap board from a stepping stone into a dead end. The IMU decides whether this logger's data is worth having, so the ₺1.194 went to the BNO055. Not revisiting.

### Upgrades — order in parallel, drop-in later

| Part | Replaces | Why | ≈ Price
Upgrade | BMP388 breakout | BMP280 | Finer altitude resolution — the elevation/grade quality jump. BMP390 is not carried in TR; BMP388 is the closest Bosch part. Robotistan (https://www.robotistan.com/bmp388-dijital-basinc-sensoru-breakout), in stock. Marginal over BMP280 — do this last, if ever. | ₺411
Upgrade | u-blox M10 / NEO-M9N GPS | NEO-M8N | True 10–25 Hz multi-constellation — best single data-quality upgrade | $20–30
Upgrade | BLE camera shutter remote | — | Handlebar marker button with zero wiring (pairs as BLE keyboard) | ₺100

Dead end — don't re-add the BNO085 (checked 2026-07-11) The BNO085/BNO080 is the better sensor (better vibration rejection, 400 Hz fusion) and this guide used to list it as the upgrade. No Turkish retailer carries it — absent from Robotistan's, Direnc's and SAMM's product sitemaps entirely. Importing is worse than the sticker price suggests: Turkey's de-minimis is €30 with 60% duty on non-EU goods, and anything over €30 leaves the simplified regime and needs a customs broker. A $24.95 Adafruit BNO085 (https://www.adafruit.com/product/4754) lands on the wrong side of that line.

Also gone: every other 9-axis fallback (MPU-9250, MPU-9255, ICM-20948) is out of stock at both Robotistan and Direnc, the Turkish-made Boardoza BNO055 (https://www.robotistan.com/boardoza-bno055-imu-sensor-modulu) (₺989,81 — the cheap bare-BNO055 play) is out of stock, and Adafruit's BNO055 at Direnc is ₺2.954,98 and out of stock. The Gravity board is the only BNO055 you can actually buy in Turkey right now — which is what justifies its price, not the DFRobot label.

### Tools you need

- Soldering iron (temperature-controlled, fine tip) + solder + flux
- Side cutters, tweezers, wire stripper
- Multimeter (continuity checks before first power-up)
- USB-C data cable + computer with Arduino IDE
- Access to a 3D printer for the enclosure (or a small project box + hobby knife)

## Wiring map

Everything is 3.3 V logic — no level shifters. The Light build is two buses (I²C, bike CAN) and the power pair. The Full build adds a second I²C bus for the OLED, the GPS UART and two buttons, all on pins Light leaves free, so nothing already soldered moves. The ⇢ bar marker means the signal leaves the rear enclosure for the handlebar.

XIAO pin | GPIO | Connects to | Bus / signal | Build
D4 | GPIO5 | 10DOF SDA (Gravity blue) | I²C bus 0 (Wire) data — BNO055 0x28 + BMP280 0x76. Rear enclosure only, ~15 cm. (The first board's D4 pad was dead and SDA lived on D3 as a workaround — see the troubleshooting note in the README) | both
D5 | GPIO6 | 10DOF SCL (Gravity green) | I²C bus 0 clock — run at 100 kHz, see below | both
D3 | GPIO4 | OLED SDA ⇢ bar | I²C bus 1 (Wire1) data — SSD1306 0x3C alone | Full
D10 | GPIO9 | OLED SCK ⇢ bar | I²C bus 1 clock — 100 kHz idle, 400 kHz frame burst | Full
D6 (TX) | GPIO43 | GPS RX ⇢ bar | UART 9600→115200 baud | Full
D7 (RX) | GPIO44 | GPS TX ⇢ bar | UART (NMEA / UBX in) | Full
D1 | GPIO2 | Screen button → GND ⇢ bar | Input, internal pull-up + 10 kΩ / 100 nF (see below). 12 mm glove button. Click = next screen · 3 s hold = toggle auto-cycling | Full
D2 | GPIO3 | Marker/zero button → GND (HW-483) ⇢ bar | Click = marker · 10 s hold = zero attitude (saved to NVS) | Full
D8 | GPIO7 | SN65HVD230 CTX | CAN TX — straight through, not a crossover like the GPS UART | both
D9 | GPIO8 | SN65HVD230 CRX | CAN RX — 250 kbit/s, listen-only (ESP32-S3 TWAI controller) | both
D0 | — | free | Former NeoPixel pin — e-bike edition uses none | —
5V (VUSB) | — | 5 V BEC +out (from the bike) | Power in — no battery; the puck boots with the bike. USB-C is for flashing only | both
GND | — | BEC −out + all module GND | Common ground — also the bike's ground via the BEC, so the CAN tap needs no extra ground wire | both
3V3 | — | All module VCC — CAN + Gravity at the rear, OLED + GPS ⇢ bar on Full | 3.3 V rail off the XIAO regulator. Full build: put a 100 µF bulk cap at the handlebar end | both

Two I²C buses, because the display moved to the handlebar The sensors ride at the rear and the OLED sits on the bar, about a metre of cable apart. Sharing one bus would drag the BNO055 — already the fragile part, already forcing the whole bus to 100 kHz — onto that long, capacitive, electrically noisy run. So they're split: bus 0 (Wire, D4/D5) stays 15 cm long inside the rear box with the BNO055 and BMP280; bus 1 (Wire1, D3/D10) carries only the OLED out to the bar.

The asymmetry is the point. A metre of cable can glitch a screen and nobody loses data; the same metre on the sensor bus costs you the ride. Firmware: Wire1.begin(D3, D10), idling at OLED_BUS_HZ (100 kHz) and bursting frames at OLED_BURST_HZ (400 kHz). If the display tears or drops out, drop the burst to 100 kHz first — that one constant is the whole debug story.

Rules for the handlebar run — a metre of I²C is not free

The handlebar box is 3.3 V only. Both things in it — the SSD1306 and the NEO-8M carrier — run off the XIAO's own 3V3 regulator. The only 5 V in the whole build is the BEC feeding VUSB inside the rear box; never run it up to the bar. That also sharpens the rules below: there's no regulator at the far end to absorb cable drop, so whatever the metre of wire loses comes straight out of the GPS's supply margin.

- Shielded multicore, shield grounded at the rear end only. Both ends makes a loop.
- SDA and SCL each twisted with their own GND return — never twisted together, they crosstalk. Same for GPS TX/RX.
- 2.2 kΩ pull-ups on the OLED bus, fitted at the ESP32 end, replacing the module's 4.7–10 kΩ. A metre adds ~100 pF and weak pull-ups can't drag the edges up through it.
- 10 kΩ to 3V3 + 100 nF to GND on D1 and D2, at the ESP32 end. The internal pull-up is ~45 kΩ; a metre of wire on that is an antenna for BEC and controller switching noise, and you get phantom presses.
- 100 µF at the handlebar end, across 3V3/GND near the GPS. Its acquisition current spikes into the cable inductance otherwise sag the rail and lengthen time-to-fix.
- ≥ 26 AWG on 3V3 and GND. The bar end draws ~60 mA — only ~16 mV of drop at 26 AWG, but thin 30 AWG hookup wire more than doubles it, off a rail with no headroom to spare.
- Longer than a metre? The pull-up and the bus capacitance set the rise time, which must stay under 1 µs at 100 kHz, while the sink current (3.3 V ÷ R) must stay under 3 mA. At ~100 pF per metre that gives 2.2 kΩ to ~2 m and 1.5 kΩ (2.2 mA sink) to ~3 m; past 3 m the 400 pF bus-capacitance ceiling binds and no pull-up value saves it. Beyond 2 m also pin OLED_BURST_HZ at 100 kHz.
- Don't reach for an I²C buffer. The arithmetic above covers any run a motorcycle actually needs, and both usual parts are unobtainable domestically — the P82B715 is obsolete and the P82B96 shows zero stock at 4–6 weeks' lead. Switching the display to SPI to dodge the issue is worse: it turns an 8-core cable into a 12-core one, and 12 × 0.14 mm² shielded is ~7.5 mm of stiff cable that will fatigue at the steering head.
- Keep the cable thin. 8 × 0.14 mm² (≈26 AWG) shielded is ~6 mm OD and stays flexible. 0.14 mm² carries the ~60 mA with room to spare, so there is no reason to go thicker and every reason not to.

GPS UART needs none of this — 115200 baud push-pull point-to-point is happy over several metres. And moving the GPS to the bar satisfies the ≥ 15 mm antenna rule for free, since the ESP32 stays at the rear.

The BNO055 + ESP32 I²C clock-stretch problem — read before you solder The BNO055 stretches the I²C clock in a way ESP32 I²C peripherals handle badly. It's the single most-reported gotcha with this chip. The usual escape is to run the BNO055 over UART instead. The Gravity connector is VCC/GND/SDA/SCL, I²C only (https://wiki.dfrobot.com/sen0253/) — but correction (2026-07-21, verified on the physical V1.0 board): the back-side pad row does break out PS1/PS2 (plus NBOOT/RST/INT/I2C_ADDR/BL_IND — no SDA/SCL pads), so a UART fallback technically exists via the PS pads. It would strand the I²C-only BMP280 on a separate bus, and the clean 10-minute hammer test made it moot — noted here in case a future revision ever needs it.

Mitigations, in order: drop the bus to 100 kHz (Wire.setClock(100000)), raise the I²C timeout (Wire.setTimeOut()), keep SDA/SCL runs short with 4.7 kΩ pull-ups. This is workable — but prove it on the breadboard before the case is glued (build step 2).

If every I²C device looks dead at once — check the pad, not the wiring The first XIAO used in this project had its D4 pad clamped low: it read 0 even with the internal pull-up enabled and nothing attached, shorted to ground somewhere on the board. An I²C line that cannot idle high is a bus no device can ever signal on, so the symptom is four simultaneously dead sensors — which reads like a wiring disaster or four bad modules, not one bad pin. SDA ran on D3 as a workaround until that board was replaced; the pin map above is back on the default pads.

How to tell a dead pad from a wiring fault: pull the pin up, then down, and read it back. A pad the chip still controls follows both (1 then 0). One that reads 0 against the internal pull-up is being held to ground by something outside the GPIO. Sweep the whole pad row rather than testing one pin — a single pin reading oddly is a story about a broken test, but the same test passing on six neighbours and failing on one names the fault. padSweep() in firmware/bench_imu_can/ does exactly this on every boot, and firmware/i2c_diag/ localises it further with normal and swapped bus scans.

Run it 6-axis (IMU mode), not 9-axis (NDOF) NDOF mode needs a calibrated magnetometer. On a motorcycle — steel frame, alternator, speaker magnets — that calibration is junk and yaw will wander. You don't need it: Tripper takes heading from GPS, and the reference-quaternion math makes absolute yaw irrelevant. OPERATION_MODE_IMUPLUS sidesteps the BNO055's worst weakness. The magnetometer is the one part of this board you paid for and won't use.

IMUPLUS makes the accelerometer load-bearing — calibrate it Six-axis is the right mode, but it removes the magnetometer, and with it the only other absolute reference. The accelerometer is then the only thing that knows where down is, and every lean and slope number is anchored to it. An uncalibrated one does not fail loudly; it biases attitude quietly for the whole ride.

So: call setExtCrystalUse(true) — the fusion modes want the board's 32.768 kHz crystal, not the internal RC oscillator — read getCalibration(), and do not accept a mount zero until the accelerometer reads 3/3. Save the offsets with getSensorOffsets() once they get there and restore them at boot, so it is a once-per-chip chore rather than once-per-ride. To calibrate: leave the bike still and upright on level ground for a few seconds. No waving about — that dance is for the magnetometer, which this mode never uses.

Antenna rule (this decides your GPS quality) Mount the GPS patch antenna at the top of the handlebar enclosure, facing the sky. The ≥ 15 mm separation from the ESP32 comes free now that the module lives at the rear — but keep it clear of the OLED ribbon and the USB cable too.

### Connectors — two harnesses, deliberately different

Two enclosures means two cable runs. They're different sizes on purpose: you cannot cross-plug them.

Run | Conductors | Connector
Bike → rear box | +5 V, GND, CAN_H, CAN_L | M8 4-pin, IP67
Rear box → handlebar box | 3V3, GND, SDA, SCL, GPS TX, GPS RX, btn1, btn2 | M12 8-pin A-coded, IP67

The two runs carry different voltages — 5 V into the rear box, 3.3 V onward to the bar — which is a second reason to keep the connectors different sizes.

Gender follows the live side Whichever end stays energised when the pair comes apart gets the female sockets — recessed contacts can't short against the frame. On the bike run that's the cable (it runs back to the BEC), so the rear enclosure carries a male panel receptacle and the cable carries a female plug. The handlebar run is dead on both sides once the bike connector is pulled, so either orientation is safe there; keep the panel male for consistency.

Parts verified in stock domestically (July 2026): rear panel ATTEND 219A-04MSR ≈ ₺243, bike cable SIGNAL ASM08AF04001 ≈ ₺282. Adding a second break so the BEC and CAN tap separate from the 4-core costs ASM08AM04001 + another ASM08AF04001 — but these field-assembly bodies take a single cable gland, so the BEC pair and CAN pair must merge into one jacket before the connector regardless. Unless that junction genuinely needs to come apart, solder plus adhesive-lined heat-shrink is more vibration-tolerant, better sealed, and free.

Keep the pin assignment identical at both ends of every run. With two connectors in one harness it is very easy to mirror one and feed 5 V into CAN_H.

## Bike CAN bus

The bike broadcasts everything the puck's own sensors can't see — pack voltage, per-cell balance, motor current, state of charge, rider controls. Reading it costs one 3.3 V transceiver and two wires.

Never connect USB and the bike at the same time Once CANH/CANL are spliced in, the puck's ground is the bike's ground — shared through the BEC's negative rail. Attaching a mains-earthed computer ties the traction battery's negative to protective earth through your machine. Worse, the BEC drives 5 V into the XIAO's 5V (VUSB) pin; plug a USB host in on top of that and two 5 V rails collide on the same node.

Unplug the M8 4-pin bike connector before you attach USB. It carries +5 V, GND, CANH and CANL together, so pulling it isolates both hazards in one action — it replaces the 2-pin CAN-only break earlier revisions called for. Read telemetry over BLE instead of serial — the puck is a BLE device; use what it already does.

Remove the module's 120 Ω terminator before you connect it Nearly every SN65HVD230 breakout carries a terminating resistor across CANH/CANL — on the Alkatronik board it is the SMD part marked 121 sitting between the two CAN pads. ISO 11898-2 puts 120 Ω only at the two ends of a bus, and the bike is already terminated at both: measure across the pair with the bike off and you get 60 Ω. Adding a third resistor makes it 40 Ω, which degrades reception and throws errors on a bus you do not own.

Desolder it (or crush it — nothing else shares that net), then confirm the module reads open across CANH/CANL before wiring it in.

Module pin | Goes to | Note
3V3 | 3V3 rail | 3.3 V part — this is why it suits the ESP32 and an MCP2551 does not
GND | GND rail | —
CTX | D8 | Straight through, not crossed. CTX is the transceiver's input
CRX | D9 | CRX is its output
CANH | bike CAN_H | Idles ~2.5 V; reads slightly higher than CAN_L on a DMM while traffic flows
CANL | bike CAN_L | Swapping H/L is harmless — you simply get zero frames. Just swap back

No ground wire in the CAN tap Only two wires reach the bike harness. The puck and the bike already share a ground through the BEC's negative rail, so a third wire in the CAN tap would just add a redundant loop. This is also why a laptop on mains is such a problem: it introduces a second ground path.

Listen-only, in firmware and by intent The ESP32-S3's TWAI controller runs in TWAI_MODE_LISTEN_ONLY: it never transmits and never even ACKs, so no firmware bug can disturb the bike's controller. Bring-up is non-fatal — if the transceiver is unplugged the puck still boots and streams GPS/IMU exactly as before, and the CAN block in the telemetry packet stays zeroed with its live bit clear.

The bus, once you find it 250 kbit/s, standard 11-bit IDs, 15 messages, ~92 frames/s. Signal decodes and the evidence behind each one live in tools/talaria.dbc; tools/can_sniff.py is the host-side kit that produced them. Three fields look like something they are not — 0x103[0] is state of health (pinned at 100), 0x202[6:8] is a free-running counter and not an odometer, and 0x490[0] tracks ride mode rather than temperature. No odometer was found on the bus.

0x490[0] turned out to be two fields, which is why it correlated with mode so strongly without ever being only mode: bits 5:3 echo the ride mode and bits 2:0 carry the regen level, 1–4. Verified 2026-07-30 over 10 button presses in two captures, one of them a descending 4→3→2→1 sweep so it cannot be a counter that happened to line up. Mask 3 bits, not the low nibble — in Eco bit 3 is set, so regen 1 reads 0x09.

## Build sequence

Bench-verify every module before final soldering — debugging inside a stacked sandwich is misery.

Light build: steps 1, 2, 3, 5, 6, 7, 8, 9 — skip step 4 (GPS) entirely. Full build: all nine in order. Because the Full build is additive, you can ship a Light build now and come back to step 4 later without unsoldering anything.

### Flash-test the XIAO

1. Arduino IDE → add ESP32 boards (Boards Manager URL: espressif/arduino-esp32), select XIAO_ESP32S3. Upload Blink. Confirm the serial monitor works at 115200.

### Breadboard the I²C sensors — this is the go/no-go gate

2. Wire the 10DOF board, run an I²C scanner at 100 kHz. Expect 0x28 (BNO055) and 0x76 (BMP280). Then hammer the bus: read the BNO055 continuously for 10 minutes straight and confirm zero dropped/hung transactions.
  Do not proceed until this is clean. The clock-stretch issue above has no UART fallback on this board — if the bus won't hold steady on a breadboard, it will not hold on a vibrating handlebar, and you need to know that now, not after the case is glued.
  ✅ Passed 2026-07-21 — 59,722 reads / 0 errors / 10 min @ 100 kHz, IMUPLUS active, max transaction 2.58 ms. Sketch: firmware/i2c_gate/.

### Prove the fusion output

3. Adafruit BNO055 library → set OPERATION_MODE_IMUPLUS (6-axis) and read getQuat(). You should see live quaternions with no calibration dance. This is the moment the project becomes real: those quaternions feed the same reference-frame math as the Tripper app — and unlike the MPU-6050's DMP, you didn't have to fight for them.
  ✅ Passed 2026-07-21 — library path up in IMUPLUS, live quaternions + linear accel on the breadboard (test sketch since folded into firmware/tripper_puck/). Bonus: MON-VER unmasked the "NEO-M8Z" GPS as genuine u-blox 8 silicon (ROM 3.01, SPG 3.01, PROTVER 18, GPS/GLO/BDS/QZSS).

### Get a GPS fix — Full build only, skip for Light

4. Wire GPS to UART, run a TinyGPS++ example near a window or outside — first cold fix can take 1–5 min. Then send the UBX commands to raise the rate to 5–10 Hz and baud to 115200 (one-time config, saved to the module's flash/battery-backed RAM).
  ✅ Fix acquired 2026-07-21 — NMEA + TinyGPS++ verified, MON-VER confirms genuine u-blox 8 (ROM 3.01, PROTVER 18, GPS/GLO/BDS/QZSS). Config applied & verified same day (firmware/gps_config_5hz/): CFG-RATE 200 ms ACKed, read-back confirmed, saved to BBR, measured 5.0 GGA/s at 115200. Production firmware re-applies at every boot in case the backup battery ever drains. Bench extra that got promoted: 0.91" SSD1306 OLED at 0x3C — bench-proven on the shared bus, since moved to its own Wire1 (D3/D10) for the handlebar run — now integral to firmware/tripper_puck/ (clock/data screens, hold toggle, zero progress UI).

### Bring up the CAN bus

5. Remove the SN65HVD230's onboard 121 terminator (see the Bike CAN section), wire CTX→D8 / CRX→D9, and tap CANH/CANL at the controller. Flash firmware/can_probe/ — it brings TWAI up at 250 kbit/s listen-only and reports a decoded dashboard on the OLED and over BLE (device Tripper-CAN, Nordic UART).
  Read wirelessly, not over serial — once CANH/CANL are spliced in you must never also attach a USB host (see the warning in the Bike CAN section). Zero frames on the OLED almost always means CANH/CANL are swapped: harmless, just swap them.
  ✅ Verified on the bench 2026-07-23 — Talaria bus decoded end to end: 250 kbit/s, 15 IDs, and the module reproduced the reference numbers (81 %, 64.3 V, kickstand, ride mode) captured independently with a USB-CAN dongle.

### Integrate the firmware

6. Flash the sketch for your build — firmware/tripper_light/ or firmware/tripper_puck/ (architecture below). Bench-test by shaking the puck and watching the telemetry stream in a BLE scanner. The Light build needs only Adafruit BNO055, Adafruit BMP280 and NimBLE-Arduino; the Full build adds Adafruit SSD1306 and TinyGPSPlus.
  ✅ e-bike edition firmware running (2026-07-21, CAN added 2026-07-23) — firmware/tripper_puck/: BLE service (telemetry 5 Hz / status 1 Hz / control), OLED screens (clock / data / bike-CAN, stepped by D1), marker button, 10 s mount-zero (reference quaternion, persisted to NVS, applied to display and telemetry), GPS autoconfig at boot, and listen-only CAN folded into the 70-byte telemetry packet. Phone-verified with LightBlue: connect, notify stream, control writes all working.

### Solder the stack

  - Shorten all wires to final lengths; silicone wire tolerates vibration best.
  - BEC +out → the XIAO 5V (VUSB) pin, BEC −out → GND. Heat-shrink everything; the BEC's input taps the bike's pack / accessory line.
  - Light build: put a 2-pin connector in the CANH/CANL run so you can isolate the bike before ever attaching USB to flash. One box: XIAO, SN65HVD230 on a short pigtail, Gravity board on foam.
  - Full build: terminate the bike run in the M8 4-pin connector (male on the panel), same purpose. Terminate the handlebar run in the M12 8-pin connector — fit its passives while the boards are still accessible: 2.2 kΩ OLED pull-ups and the 10 kΩ / 100 nF button networks at the rear end, the 100 µF bulk cap at the bar end. Handlebar box: OLED window, both buttons in the lid, GPS under a thin lid section.

### Enclosure & mounting

  - Light build — one enclosure at the rear near the controller tap: ESP32, CAN module, sensor board. Nothing goes on the handlebar, so there is no second case, no bar cabling and no antenna placement problem.
  - Full build — two enclosures, split rear / handlebar: the ESP32, CAN module and sensor board ride at the rear; the OLED, two buttons and GPS sit at the handlebar (the GPS wants sky view, the screen wants your eyeline).
  - Rear case ≈ 55 × 40 × 22 mm; cutouts: USB-C (flashing), the CAN + BEC leads, and on Full the M8 4-pin panel receptacle for the bike plus the M12 8-pin for the handlebar run. Check your wall thickness against the connector's thread depth — M8/M12 panel jacks typically want ≤ 2–3 mm.
  - Handlebar case (Full only): OLED window, two button cutouts, a sky-facing 1.5 mm lid section over the GPS patch, and the M12 cable entry. No USB port here.
  - Sensor board sits on the 2 mm foam pad — isolates handlebar buzz from the accelerometer.
  - GPS antenna under a 1.5 mm lid section (plastic is RF-transparent), ESP32 at the opposite end.
  - Mount the cases rigidly to the bar/frame (the foam is inside, not outside) — same rule as the phone.

### Field-verify against Tripper

9. Ride with the puck and the phone app recording simultaneously. The CAN block should carry live battery %, pack voltage, ride mode and regen level, and orientation should track the bike's lean. Compare in the app — the BLE stream is the only data path, there is no file to import.
  Full build: distances should agree within a few percent and the puck's 5 Hz track should look smoother in corners than the phone's 1 Hz. Light build: position comes from the phone, so there is no second track to compare — verify instead that orientation, g-force, barometric altitude and the whole CAN block land in the recording, and that caps reads 0x08 so the app knows to keep using phone GPS.

## Firmware architecture

Arduino (C++). One loop, three rates, no RTOS needed. Two sketches: tripper_light/ and tripper_puck/.

Two sketches, one wire format tripper_puck/ is the Full build. tripper_light/ is the same firmware with the GPS, OLED and button code removed outright — not disabled by a flag, so the Light build carries no dead weight and needs two fewer libraries. What stays identical: service UUIDs, the 70-byte telemetry packet, the 14-byte status packet, and the whole CAN decode.

A Light puck fills the GPS block with zeros and leaves both flags bits clear — indistinguishable from a Full puck that hasn't got a fix yet, which the app already handles — so no app branch is required. The status packet's last byte, previously reserved, now carries capability bits: 0x08 from Light, 0x0F from Full. Zero means firmware older than the field, which is why "has CAN" is an explicit bit rather than assumed.

The cost of two sketches is drift. Each is standalone, so the packet structs and CAN decode exist twice. Anything touching the wire format must land in both — README.md → Build & flash carries a one-liner that diffs the two field lists and should print nothing.

### Libraries

Library | For | Build
Adafruit BNO055 + Adafruit Unified Sensor | Quaternions, linear accel & gravity vector at 100 Hz — fusion runs on the chip | both
Adafruit BMP280 | BMP280 pressure → altitude | both
NimBLE-Arduino | BLE link to the Tripper app | both
driver/twai.h (ESP-IDF, bundled) | On-chip CAN controller — listen-only, no external library | both
Preferences (bundled) | Persist the mount-zero reference quaternion to NVS | both
TinyGPSPlus | NMEA parsing (lat/lon/alt/speed/course/hdop/time) | Full
Adafruit SSD1306 + Adafruit GFX | 0.91" OLED — clock / data / bike-CAN screens | Full

### Main loop (rates)

every pass  GPS: drain the UART into TinyGPS++        (Full only)
           CAN: drain the TWAI RX queue (bounded to 16 frames/pass),
                latch the newest payload of each decoded ID

100 Hz  IMU: read BNO055 quaternion (fusion already done on-chip)
        → reference-frame math
        (same as Tripper: slope = asin(fwd_world.z), g = dot products)
        latch interval max-g

  5 Hz  TELEMETRY: assemble the 70-byte packed sample (GPS + IMU +
        the CAN block, zeroed unless a frame arrived in the last 2 s)
        and BLE-notify it

  1 Hz  HOUSEKEEPING: BLE status notify, baro sample, serial debug line

No SD, no CSV, no auto-record state machine — those moved to the phone. The puck is a stateless sensor: it streams, the app records and decides when a ride is running (and tells the puck over the control characteristic, which is what flips the OLED into trip-time mode).

### Buttons — Full build only

The Light build has none: a marker arrives as control write 0x01 and mount-zero as 0x02, both from the app. On Full, 0x01 is only an ack for a press the button already counted; on Light it originates the marker, since nothing else can.

Both sit on pin-change ISRs with 50 ms debounce, so presses land even while the loop is stalled. Each discriminates click from hold the same way: the ISR timestamps the press and counts a click only if the release lands inside 600 ms, so a long hold never also fires a click.

D1 (12 mm glove button) — click steps to the next OLED screen · 3 s hold toggles auto-cycling. Screens do not rotate on their own by default: on a moving bike the screen you picked should stay put.

D2 (HW-483) — click drops a marker into the telemetry packet · 10 s hold zeroes roll/pitch/yaw and saves the reference quaternion to NVS.

### Status — all on the OLED (Full build)

The Light build has no indicator at all — not even a status LED — so everything below is Full-only. That is deliberate rather than a gap: the phone is already in the rider's pocket running the app, and the OLED exists to save you pulling it out. A Light puck reports its health entirely through the 1 Hz BLE status packet.

There is no status LED (the NeoPixel was dropped). Everything reads off the 0.91" screen: a fix dot (hollow → solid on lock), LINK/ADV for the BLE state, satellite bars, MARK and ZEROED splashes, and the bike-CAN screen's own no data / off indicator. During a ride (app-driven) the whole display inverts and a trip-time screen joins the rotation.

### On-air format — the BLE telemetry packet

There is no file. The data leaves as a 70-byte packed little-endian sample notified at 5 Hz — GPS, quaternion, linear/max g, marker, then the bike-CAN block (speed, rpm, power, current, pack voltage, battery %, throttle demand, cell high/low, kickstand, ride mode, regen level). The app's ExternalSensorSource feeds it into the same recorder pipeline the phone sensors use. Full offset table: see README.md → BLE protocol.

Identical on both builds, byte for byte. On a Light puck the GPS fields are zero and flags bits 0–1 are clear, gpsTimeMs is 0xFFFFFFFF and hdop_c is 9999 — the app must gate on those bits anyway, because a Full puck looks the same indoors. Read caps in the status packet to know whether position will ever arrive, and fall back to phone GPS when bit 0x01 is clear.

## Power

No battery. The puck runs off the bike through a 5 V BEC, so the only question is whether the BEC has margin — and it has a lot.

Consumer | Typical draw
ESP32-S3 (BLE active) | ≈ 40–70 mA
GPS (NEO-8M, tracking) | ≈ 30 mA
OLED | ≈ 10 mA
IMU + barometer | ≈ 4 mA
SN65HVD230 (listen-only) | ≈ 5 mA
Total ≈ 100–150 mA against a 3 A BEC | < 5% load

The BEC is oversized on purpose — headroom for inrush at boot and for a phone charging off the same outlet if you ever add one. The one thing to check on your bike: that the BEC's input line stays live at standstill and doesn't cut at low load, or the puck drops out every time you stop.

## The Bluetooth link to Tripper

The puck is a live sensor for the app — this is the product, not a future phase.

One BLE service (Tripper-DL1), three characteristics:

Characteristic | Direction | Payload
telemetry | notify → phone | 70-byte packed sample @ 5 Hz: fix, lat, lon, alt, speed, course, quat, g, baro, marker + the bike-CAN block
status | notify → phone | 14 bytes @ 1 Hz: fix quality, sats, uptime, temperature, marker
control | write ← phone | marker ack · zero attitude · identify · ride state (active + elapsed)

App side: an ExternalSensorSource that feeds the same recorder pipeline the phone sensors use today — the dashboard, Dynamic Island, overlays, and exports all work unchanged, now with 5 Hz GPS and the bike's own battery/drivetrain data. The phone's Marker button stamps markers into both logs. Exact byte layout and control opcodes: README.md → BLE protocol.

## Pitfalls — read before soldering

- BEC vs USB — never both: the BEC feeds 5 V into VUSB. Plugging USB in while the BEC is powered collides two 5 V rails and, with the CAN tap connected, bridges the bike's ground to mains earth. Unplug the M8 4-pin bike connector before flashing — it kills power and CAN in one pull.
- Don't share one I²C bus with the handlebar: the OLED belongs on Wire1 (D3/D10), not on the sensor bus. Hanging a metre of cable off D4/D5 risks the BNO055, and a flaky sensor bus costs data — a flaky display costs nothing.
- Phantom button presses: a metre of wire on a 45 kΩ internal pull-up picks up controller noise. Fit the 10 kΩ / 100 nF network on D1 and D2 at the ESP32 end before you blame the firmware.
- Torn or blank OLED after the extension: drop OLED_BURST_HZ to 100 kHz first, then check the 2.2 kΩ pull-ups, then check that SDA and SCL aren't twisted with each other.
- CAN terminator: remove the module's onboard 121 (120 Ω) resistor — the bike's bus is already terminated at 60 Ω and a third makes it 40 Ω. Measure open across CANH/CANL before wiring in.
- CANH/CANL swap: harmless but silent — you just get zero frames. If the probe shows no data, swap the pair first.
- BEC dropout at standstill: confirm the BEC's input line stays live when the bike is stopped, or the puck reboots every time you stop.
- GPS near ESP32: keep antenna ≥ 15 mm from the module and USB cable; test fix time before gluing anything.
- Fake u-blox: ultra-cheap marketplace "M8N" boards are often older chips reflashed — buy from drone shops; verify with u-center over serial.
- Vibration: foam under the sensor board or your g-force column is engine buzz.
- Waterproofing: conformal coat the boards or accept "shower-proof"; keep the USB port plugged with a rubber stopper.

Tripper Puck build guide · companion hardware for the Tripper iOS app (https://github.com/kbirand/Tripper) · sensor math shared with ReferenceFrame.swift

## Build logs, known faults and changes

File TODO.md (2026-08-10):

# Open issues

## Lean and slope are still wrong, and the cause is not yet known

**Status:** open, investigation logged in
[`docs/lean-investigation.md`](docs/lean-investigation.md). Read that before
touching attitude code.

Five hypotheses have been tested and eliminated — mount/axes/zero, gyro drift,
the frame algebra, the bike's own acceleration, vibration level — and two
explanations were offered and withdrawn. The gyro, the mount and the barometer
are all confirmed healthy; the absolute angle out of the BNO055's fusion is
not. Firmware v0x04 puts the raw accelerometer on the wire so the next ride can
tell "the chip is fed bad data" from "the chip mishandles good data", which
this one could not. The file lists exactly what to check when that ride lands.

## Connector topology for the handlebar run is out of date in the docs

**Status:** decided in discussion, not yet reflected in the documentation.

The docs currently describe the rear-to-handlebar link as **two panel-mount M12
receptacles** — one in each enclosure. That is wrong on its own terms: two panel
receptacles mate face to face, so there is no cable between them. A panel-only
pair would need two additional cable-end plugs to become a working harness, and
no M12 8-pin cable-end plug could be found in stock domestically.

The part actually sourced is a [Motorobit M12 8-pin
set](https://www.motorobit.com/m12-8-pinli-konnektor-seti) (≈ ₺691, IP67, 4–6 mm
cable entry). **Both halves of that set are cable-end**, not panel — so the real
topology is an in-line coupler:

```
[handlebar box] ══cable══► (female) ╪ (male) ◄══pigtail══ [rear box]
        ↑                                              ↑
      gland                                          gland
```

That is **2 glands + 1 in-line connector pair**, not 1 panel + 1 plug.

### What needs changing

| File | What is stale |
|---|---|
| `README.md` | "Connectors" section — the M12 row and the gender-follows-the-live-side paragraph (that rule applies to the M8 bike run only; the handlebar run is dead on both sides once the bike connector is pulled) |
| `hardware/build-guide.html` | "Connectors — two harnesses, deliberately different" section, the shopping-list M12 row, and build step 7 ("Terminate the handlebar run in the M12 8-pin connector") |
| `wiring-schema.jpg` | Callout ⑤ still reads as a panel connector at the enclosure boundary |

### Consequences to carry into the rewrite

- **Cable choice narrows.** The 4–6 mm gland rules out full S/FTP Cat6 (~6.0–6.2 mm).
  Use **F/UTP stranded Cat5e/Cat6 patch, ~5 mm**. Stranded, not solid — solid
  copper work-hardens and breaks under vibration.
- **The shield cannot cross the connector.** The body is plastic and all 8
  conductors are in use, so there is no path for a 360° shield termination.
  Bond the shield to GND **in the handlebar box only** and cut it back at the
  connector. This reverses the "shield at the rear end only" rule currently in
  the docs — what matters is that it is grounded at exactly one end.
- **Mechanical:** an in-line connector left hanging fatigues its own cable
  entries. Secure it to the frame with a P-clip.
- Pair assignment is unaffected: `3V3+GND / SDA+btn1 / SCL+btn2 / GPS TX+RX`.
  SDA and SCL must stay in separate pairs.

### Not affected

The M8 bike connector (ATTEND 219A-04MSR panel male + SIGNAL ASM08AF04001 cable
female) is unchanged, and so is the gender rule for it: the cable side runs back
to the BEC and stays live, so it gets the female sockets.

`hardware/tripper-puck.fzz` is also unaffected — it models each connector as a
mated pass-through, which is true regardless of whether the body is panel-mount
or in-line.

## Bike control: mode works on the bike, regen is unverified

**Status:** **mode control works on the bike.** Built, flashed over WiFi and
confirmed 2026-08-10 with the bike on a stand: the app sets the mode and the
machine obeys. Regen is built and shipped alongside it but is **still
unverified** — see the spin-down test below. The evidence lives in
[`tools/talaria.dbc`](tools/talaria.dbc) (`0x490`, `0x402`) and the CAN sections
of both READMEs; read those before touching this.

`0x490` is a **command from the dash to the controller**, not the echo it was
labelled as for months. The puck now answers each of the dash's frames with the
overridden value. Measured on the bike over ~1000 transmits: `tx` climbs by
exactly 5/s (one reply per dash frame, no waste), `txerr=0`, `boff=0`, driver
never leaving `run`. `rxerr` blips to 4–5 and self-clears, which is what two
nodes sharing an arbitration ID look like.

### The bike's display cannot be made to agree — this is permanent

The dash renders its own internal state and ignores the bus entirely. It ignores
the **controller's** frame too, not just ours: through the 30 s injection test
`0x202` reported Eco for the full duration while the screen stayed on Sport. No
CAN message can update that display, from the puck or from anything else.

So while an override is held the bike carries two disagreeing instruments, and
the **app is the honest one** — its mode comes from `0x202`, the controller's own
report. Do not "fix" this; there is nothing to fix it with. The mitigation is
already in the firmware: pressing the handlebar button releases the override and
realigns the display, so the disagreement can never get stuck.

### Regen needs a turning wheel, not a ride — test it before building

An earlier version of this entry said regen could not be confirmed until the
firmware shipped, and made the build order depend on it. That was circular and
wrong twice over. **The rider can already change regen with the handlebar
button**, and the injected-regen test runs from the Mac over the USB-CAN-A,
which is the same rig that proved the mode override. Neither waits on firmware.

It also does not need a ride. It needs a *turning wheel*:

> Bike on a paddock or centre stand, rear wheel free, kickstand up. Throttle to
> ~20 km/h indicated, release, and log `0x303` through the spin-down. Repeat at
> regen 1 and regen 4.

Two runs with the handlebar button answer **"does regen level change the
deceleration at all?"**. Two more with `can_sniff.py` injecting a different
level than the dash is showing answer **"does the controller honour an injected
level?"** — which is the only question that gates the feature.

An unloaded wheel is a poor model of road braking; it has almost no inertia and
the numbers will not resemble real deceleration. That does not matter. The test
asks whether the injected level *changes* the spin-down, not whether it changes
it realistically, so a difference is the entire result.

**If every level spins down identically**, regen is probably triggered by the
brake lever rather than by throttle-off. Retry pulling the *front* lever only,
so the rear mechanical brake does not mask the rear motor's regen.

### The ride that settles the rest

What is genuinely left for a ride, once the bench test above has run:

1. **Odometer** — currently **provisional**. It rests on a single static match:
   the bike's display read 400 km and `0x402[2:4]` read exactly 400. This bus
   carries round constants (1200 sits in both `0x101[4:6]` and `0x302[6:8]`),
   so one match against a round number is suggestive, not proof. 1–2 km of
   riding must move the field.
2. **Regen under load** — only worth doing *after* the bench spin-down has
   shown the controller honours an injected level. The bench answers whether
   the command lands; a road coast-down at regen 1 versus 4 answers whether it
   feels like anything with the bike's own mass behind it. Needs a recorder on
   the moving bike, so it wants the puck flashed first.
3. **Mode override under load** — confirmed on a stand (Eco capped the bike at
   44 km/h, Sport at 80), but a wheel in the air is not the road. Worth one
   check that it holds under real load.

### What is already proven, so nobody re-derives it

- **Reactive injection is the technique.** The controller obeys whichever
  `0x490` it heard last and never latches. Free-running at 20 Hz against a dash
  sending 5 Hz still lost 24% of samples — the current limit oscillating
  between 750 and 1100 several times a second. Replying the *instant* the dash
  speaks held **297/297** of the controller's own frames over 30 s, at a third
  of the traffic.
- **Release is fail-safe and free.** The bike reverts to the dash's choice
  within 100 ms of the last injected frame, so a dropped BLE link, a crashed
  app and a wedged puck all land in the same safe place.
- **The dash never listens.** It renders its own state, so an overridden bike
  disagrees with its own screen for as long as the override lasts. The app
  shows the truth for free — mode reaches the packet from `0x202`, the
  controller's frame — but **regen reaches it from `0x490`**, the dash's frame,
  which the puck cannot hear itself transmit. Under a regen override the app
  must display what it commanded, not what it overheard.
- **The puck stops being read-only.** `TWAI_MODE_LISTEN_ONLY` becomes
  `TWAI_MODE_NORMAL` in both `.ino` files. "It never transmits, so it cannot
  disturb the bike" stops being true, and both READMEs claim it in those words.

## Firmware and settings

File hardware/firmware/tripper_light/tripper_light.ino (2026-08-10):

// ============================================================
// Tripper Puck — LIGHT BUILD firmware
// ============================================================
// The rear unit only: IMU + barometer + bike CAN, streamed over BLE. No GPS,
// no OLED, no buttons — nothing on the handlebar. The phone is the recorder
// AND the position source; this firmware never claims a GPS fix.
//
//   100 Hz  BNO055 quaternion + linear accel (IMUPLUS), latch interval max-g,
//           gyro/raw-accel window sums (the packet sends the 200 ms mean)
//   5 Hz    BLE telemetry notify (88-byte packed sample, same layout as Full)
//           + BMP280 baro sample
//   1 Hz    BLE status notify, baro temperature, serial debug line
//   10 Hz   BLE raw notify — the 100 Hz IMU samples themselves, un-averaged,
//           batched ten at a time with the puck's own timestamp (see RawBatch)
//   ~92/s   Talaria CAN frames, listen-only (SN65HVD230 on D8/D9)
//
// WIRE-COMPATIBLE WITH THE FULL BUILD ON PURPOSE. Identical service UUIDs,
// identical 88-byte telemetry packet, identical 15-byte status packet, and the
// same 148-byte raw batch. (This paragraph said 78 and 14 for months after the
// packets grew — if you change a struct, change this line in the same commit.)
// The app needs no branch: the GPS block simply arrives zeroed with both flags
// bits clear, which is the same "no fix" state the Full build reports indoors, and
// the app already has to gate on those bits. Capability bits in the status
// packet say which build is on the other end (see StatusPacket::caps).
//
// What moves to the app in this build:
//   - position, speed, course      -> phone GPS
//   - marker                       -> control write 0x01 (no button here)
//   - mount zero                   -> control write 0x02 (no button here)
//   - all status//screens          -> the app's own UI (no OLED here)
//
// Keep this file's CAN decode, packet structs and UUIDs in step with
// tripper_puck.ino. Signal provenance lives in tools/talaria.dbc.

#include <Wire.h>
#include <Adafruit_Sensor.h>
#include <Adafruit_BNO055.h>
#include <Adafruit_BMP280.h>
#include <NimBLEDevice.h>
#include <Preferences.h>
#include <driver/twai.h>
#include <WiFi.h>
#include <ArduinoOTA.h>
#include <WebServer.h>
#include <Update.h>
#include <esp_system.h>

// ---------- OTA (flashing over WiFi) ----------
// The puck lives inside an enclosure on the bike, so every USB flash means
// dismounting it. Instead the puck raises its OWN network on demand: the app's
// Settings toggle (control write 0x05 — this build has no buttons) starts a
// SoftAP; the computer joins it, and the puck appears as a NETWORK PORT in
// Arduino IDE (Tools -> Port -> "tripper-light at 192.168.4.1"). Upload works
// from the desk with the puck still on the bike, anywhere — no home-network
// credentials in the firmware, nothing to configure per location.
//
// The mode is deliberately NOT persistent: a bike power cycle always boots
// into normal riding with the WiFi radio off, so a toggle forgotten overnight
// can't leave an open AP riding around. The status packet reports the live
// state (see StatusPacket::otaState) so the app's toggle shows the truth.
// Needs a partition scheme with two app slots — the XIAO ESP32S3 default
// (8MB with OTA) is one. USB remains the recovery path if an update bricks.
#define OTA_AP_SSID     "Tripper-Light-OTA"
#define OTA_AP_PASS     "tripper-ota"   // WPA2 needs >= 8 chars
#define OTA_HOSTNAME    "tripper-light" // the network-port name in the IDE
#define OTA_PASSWORD    "tripper"       // IDE prompts for this before upload

bool otaActive = false;                 // SoftAP up, ArduinoOTA polled

// While the AP is up, the puck also serves diagnostics over HTTP — the same
// lines that go to USB serial, without the cable (this build is inside an
// enclosure on the bike; USB means dismounting):
//   http://192.168.4.1/     one-page live status
//   http://192.168.4.1/log  the last ~8 KB of debug lines, oldest first
// The ring lives in RAM from boot, so lines logged long BEFORE the toggle
// are still there when the network comes up — turn it on after something
// odd and read what the puck said at the time. Lost on power cycle.
WebServer httpd(80);
static char logRing[8192];              // zero-initialised; NULs are skipped
static size_t logHead = 0;

// printf-alike that mirrors every line to USB serial and the ring. The 1 Hz
// [dbg] line goes through here; one-off boot/event lines can too.
void logLine(const char *fmt, ...) {
  char line[320];
  va_list ap;
  va_start(ap, fmt);
  int n = vsnprintf(line, sizeof(line) - 1, fmt, ap);
  va_end(ap);
  if (n < 0) return;
  if (n > (int)sizeof(line) - 1) n = sizeof(line) - 1;
  line[n++] = '\n';
  Serial.write((const uint8_t *)line, n);
  for (int i = 0; i < n; i++) {
    logRing[logHead] = line[i];
    logHead = (logHead + 1) % sizeof(logRing);
  }
}

// ---------- pins & constants ----------
// I2C on the XIAO's default pads, stated explicitly rather than relying on a
// bare Wire.begin(). Keep in step with tripper_puck.ino.
#define PIN_SDA      D4
#define PIN_SCL      D5
#define CAN_TX_GPIO  GPIO_NUM_7   // D8 -> SN65HVD230 CTX
#define CAN_RX_GPIO  GPIO_NUM_8   // D9 <- SN65HVD230 CRX
#define CAN_STALE_MS 2000UL       // no frame for this long = bus considered dead

static const char *SVC_UUID  = "8E7C1A20-0F5A-4B9C-9C90-54B1D2A70001";
static const char *TELE_UUID = "8E7C1A20-0F5A-4B9C-9C90-54B1D2A70002";
static const char *STAT_UUID = "8E7C1A20-0F5A-4B9C-9C90-54B1D2A70003";
static const char *CTRL_UUID = "8E7C1A20-0F5A-4B9C-9C90-54B1D2A70004";
// Raw 100 Hz flight recorder. Additive: a phone that never subscribes sees the
// puck behave exactly as before.
static const char *RAW_UUID  = "8E7C1A20-0F5A-4B9C-9C90-54B1D2A70005";

// Capability bits, reported in StatusPacket::caps. A Full build sends
// GPS|OLED|BUTTONS; this build sends CAN only. Zero would be an old firmware
// that predates the field, which is why HAS_CAN is a bit rather than assumed.
#define CAP_GPS      0x01
#define CAP_OLED     0x02
#define CAP_BUTTONS  0x04
#define CAP_CAN      0x08
#define BUILD_CAPS   (CAP_CAN)

// ---------- packets (little-endian, packed) ----------
// Byte-for-byte identical to tripper_puck.ino. Do not reorder either copy.
// The wire version, in ONE place. The status page carried a hardcoded
// "packet v0x05" through two format changes and was still claiming 0x05 on a
// 0x07 puck — which sent this session chasing a firmware-version question the
// device was actively lying about. A string that describes the wire format is
// part of that format.
static constexpr uint8_t PKT_VER = 0x07;
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
void loop() {
  uint32_t now = millis();
  loopsPerSec++;
  if (lastLoopAt && now - lastLoopAt > maxLoopGapMs) maxLoopGapMs = now - lastLoopAt;
  lastLoopAt = now;

  canPoll();

  if (bleOtaMsg) {                      // 0x05: WiFi flashing mode toggle
    bleOtaMsg = false;
    otaSetMode(bleOtaOnB != 0);
  }
  if (otaActive) {
    ArduinoOTA.handle();
    httpd.handleClient();
  }

  if (bleMarkReq) {
    bleMarkReq = false;
    markerCount++;
    Serial.printf("[marker] #%d (app)\n", markerCount);
  }
  if (bleZeroReq) {
    bleZeroReq = false;
    if (imuOk) {
      // Refuse while the accelerometer is uncalibrated. In IMUPLUS it is the
      // only thing that knows where down is, so a zero taken against a bad one
      // is silently wrong for the whole ride. This build has no screen and no
      // buttons, so the app is the only place the rider can be told — it
      // checks the same calibration byte before it ever sends 0x02, and this
      // is the backstop behind that check.
      if (calAcc < 3 && !calRestored) {
        Serial.printf("[zero] refused: accel calibration %d/3 — leave the bike "
                      "still and level for a few seconds\n", calAcc);
      } else {
        qRef = tiltOnly(lastQuat);      // this orientation's TILT is the new zero
        saveQRef();
        zeroCount++;                    // the app's proof it landed
        Serial.println("[zero] mount reference captured & saved (app)");
      }
    }
  }

  // 100 Hz IMU
  if (imuOk && now - tImu >= 10) {
    tImu = now;
    // A glitched I2C read, or the chip briefly back in CONFIG mode, returns
    // something that isn't a rotation. Holding the previous sample costs one
    // 10 ms tick; letting it through corrupts the attitude outright.
    imu::Quaternion q = bno.getQuat();
    float n2 = q.w() * q.w() + q.x() * q.x() + q.y() * q.y() + q.z() * q.z();
    if (n2 > 0.9f && n2 < 1.1f) lastQuat = q;
    else                        quatRejects++;
    lastLin  = bno.getVector(Adafruit_BNO055::VECTOR_LINEARACCEL);
    lastGyro = bno.getVector(Adafruit_BNO055::VECTOR_GYROSCOPE);
    // Sampled in the same 10 ms tick as the quaternion and the linear accel, so
    // the three are one consistent snapshot — the comparison they exist for is
    // meaningless if they come from different instants.
    lastAcc  = bno.getVector(Adafruit_BNO055::VECTOR_ACCELEROMETER);
    // Accumulate for the packet means. Every 100 Hz sample now reaches the
    // app (as part of a mean) instead of 1 in 20 reaching it verbatim.
    gyroSumX += lastGyro.x(); gyroSumY += lastGyro.y(); gyroSumZ += lastGyro.z();
    accSumX  += lastAcc.x();  accSumY  += lastAcc.y();  accSumZ  += lastAcc.z();
    imuWinN++;
    // Peak departure from 1 g over the window — see accDev_mg. Latched from the
    // same snapshot as the sums, so the mean and its peak describe one window.
    double accDev = fabs(lastAcc.magnitude() / 9.80665 - 1.0);
    if (accDev > accDevMax) accDevMax = accDev;
    float g = lastLin.magnitude() / 9.80665f;
    if (g > maxG_g) maxG_g = g;

    // ---- raw flight recorder ----
    // Same tick, same snapshot as the means above: the whole point is that this
    // is the un-averaged version of exactly what the packet carries.
    if (rawEnabled) {
      if (rawN == 0) rawT0 = now;
      RawSample &s = rawBuf[rawN];
      // Clamped rather than wrapped. A saturated sample is obvious in analysis;
      // a wrapped one reads as a violent rotation that never happened.
      auto cl16 = [](double v) -> int16_t {
        return (int16_t)(v > 32767.0 ? 32767.0 : (v < -32768.0 ? -32768.0 : v));
      };
      s.gx = cl16(lastGyro.x() * 100.0);
      s.gy = cl16(lastGyro.y() * 100.0);
      s.gz = cl16(lastGyro.z() * 100.0);
      s.ax = cl16(lastAcc.x() / 9.80665 * 1000.0);
      s.ay = cl16(lastAcc.y() / 9.80665 * 1000.0);
      s.az = cl16(lastAcc.z() / 9.80665 * 1000.0);
      rawN++;
      if (rawN >= RAW_BATCH_N) {
        if (bleServer->getConnectedCount() > 0) {
          uint8_t buf[sizeof(RawBatch) + sizeof(rawBuf)];
          RawBatch *h = (RawBatch *)buf;
          memset(h, 0, sizeof(RawBatch));
          h->ver = 0x01;
          h->count = rawN;
          h->period_us100 = 100;          // 10.000 ms nominal; t0_ms is the truth
          h->t0_ms = rawT0;
          // lastQuat, not qRel(): the mount zero is an app-side convention that
          // may be re-derived later, and a log that has already applied it can
          // never be un-applied.
          h->qw = (int16_t)(lastQuat.w() * 16384);
          h->qx = (int16_t)(lastQuat.x() * 16384);
          h->qy = (int16_t)(lastQuat.y() * 16384);
          h->qz = (int16_t)(lastQuat.z() * 16384);
          h->press_pa = (int32_t)lastPressPa;
          h->temp_x10 = (int16_t)(lastTempC * 10);
          // The globals the 1 Hz status block already refreshes. Re-reading the
          // chip ten times a second would spend I2C budget this bus does not
          // have — it runs at 100 kHz because the BNO055 stretches the clock —
          // on four numbers that change over tens of seconds.
          h->calSys = calSys; h->calGyr = calGyro;
          h->calAcc = calAcc; h->calMag = calMag;
          memcpy(buf + sizeof(RawBatch), rawBuf, sizeof(RawSample) * rawN);
          chRaw->setValue(buf, sizeof(RawBatch) + sizeof(RawSample) * rawN);
          chRaw->notify();
          rawBatches++;
        }
        rawN = 0;
      }
    }
  }

  // 5 Hz telemetry
  if (now - tTele >= 200) {
    tTele = now;
    // Read the barometer here, at packet rate, not in the 1 Hz status block
    // where it used to live. Slope is fitted over a 10 m window; at 30 km/h
    // that window passes in just over a second, and a 1 Hz altitude gave it
    // barely two distinct points to fit. The BMP280 runs 63 ms standby, so a
    // fresh reading always exists. Altitude comes from the pressure just read
    // rather than readAltitude(), which would issue a second I2C transaction.
    if (bmpOk) {
      lastPressPa = bmp.readPressure();
      lastBaroAlt = 44330.0f * (1.0f - powf(lastPressPa / 101325.0f, 0.1903f));
    }
    TelemetryPacket p = {};
    p.ver = PKT_VER;                    // see PKT_VER for what it means
    // No GPS in this build. flags stays 0 and the position block stays zeroed,
    // which is the same state the Full build reports before it gets a fix — so
    // the app's existing gating covers this without a special case.
    p.flags = (calAcc >= 3 || calRestored) ? 4 : 0;
    p.gpsTimeMs = 0xFFFFFFFF;
    p.hdop_c = 9999;
    p.baroAlt_cm = (int32_t)(lastBaroAlt * 100);
    p.press_pa = (uint32_t)lastPressPa;
    imu::Quaternion qz = qRel();        // mount-zeroed, same frame as the Full build
    p.qw = (int16_t)(qz.w() * 16384);
    p.qx = (int16_t)(qz.x() * 16384);
    p.qy = (int16_t)(qz.y() * 16384);
    p.qz = (int16_t)(qz.z() * 16384);
    p.linx_mg = (int16_t)(lastLin.x() / 9.80665f * 1000);
    p.liny_mg = (int16_t)(lastLin.y() / 9.80665f * 1000);
    p.linz_mg = (int16_t)(lastLin.z() / 9.80665f * 1000);
    p.maxG_mg = (int16_t)(maxG_g * 1000);
    p.marker = markerCount;
    // Window means (ver 0x05). Falls back to the newest sample on the packet
    // that races a boot — imuWinN can only be 0 before the first 10 ms tick.
    double invN = imuWinN ? 1.0 / imuWinN : 0.0;
    double mGx = imuWinN ? gyroSumX * invN : lastGyro.x();
    double mGy = imuWinN ? gyroSumY * invN : lastGyro.y();
    double mGz = imuWinN ? gyroSumZ * invN : lastGyro.z();
    double mAx = imuWinN ? accSumX * invN : lastAcc.x();
    double mAy = imuWinN ? accSumY * invN : lastAcc.y();
    double mAz = imuWinN ? accSumZ * invN : lastAcc.z();
    gyroSumX = gyroSumY = gyroSumZ = 0;
    accSumX = accSumY = accSumZ = 0;
    imuWinN = 0;
    p.gyrx_d16 = (int16_t)(mGx * 16);
    p.gyry_d16 = (int16_t)(mGy * 16);
    p.gyrz_d16 = (int16_t)(mGz * 16);
    p.calib = (uint8_t)((calSys << 6) | (calGyro << 4) | (calAcc << 2) | calMag);
    p.zeroCount = zeroCount;
    // Raw accel in mg. ±16 g would overflow an int16 in mg, but the BNO055's
    // accelerometer runs at ±4 g in fusion mode and clips there itself, so the
    // range can't be reached. Clamped anyway: a wrapped sign on the one channel
    // that exists to be trusted is worse than a saturated one.
    p.accx_mg = (int16_t)constrain(mAx / 9.80665 * 1000, -32000, 32000);
    p.accy_mg = (int16_t)constrain(mAy / 9.80665 * 1000, -32000, 32000);
    p.accz_mg = (int16_t)constrain(mAz / 9.80665 * 1000, -32000, 32000);
    p.quatRejects = (uint16_t)min(quatRejects, 65535UL);
    // Saturates at 65 g of departure, which the ±4 g sensor cannot reach.
    p.accDev_mg = (uint16_t)constrain(accDevMax * 1000.0, 0, 65535);
    accDevMax = 0;
    maxG_g = 0;
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

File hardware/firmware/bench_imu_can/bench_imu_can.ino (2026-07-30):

// ============================================================
// Tripper Puck — bench bring-up rig: IMU + baro + bike CAN only
// ============================================================
// The production firmware assumes the whole harness is present. This one is
// for the half-built puck on the bench: no OLED, no buttons, no GPS. What it
// keeps is everything needed to prove the sensor and CAN halves are soldered
// correctly, plus the same BLE contract as production so the phone app still
// works once USB has to come out (see "two-stage test" below).
//
//   100 Hz  BNO055 quaternion + linear accel (IMUPLUS), interval max-g latch
//   1 Hz    serial health report, BMP280 sample, BLE status notify
//   5 Hz    BLE telemetry notify — same 70-byte v0x02 packet as production
//   ~92/s   Talaria CAN frames, listen-only (SN65HVD230 on D8/D9)
//
// Deliberate differences from tripper_puck.ino, all in service of bring-up:
//
//   * The BNO055 is driven directly over Wire instead of through
//     Adafruit_BNO055. On a bare bus the ESP32's weak internal pull-ups let
//     the controller sample a phantom ACK, and a library begin() that only
//     checks "did something answer" reports success against a chip that
//     isn't there. Talking to the registers ourselves means every claim in
//     the report below is backed by a byte that actually came off the bus.
//   * Every 100 Hz read is checked and counted. A cold solder joint shows up
//     as a climbing err= instead of quietly corrupt quaternions.
//   * Missing sensors are retried every 3 s, so you can solder a wire with
//     the rig running and watch it come alive without a reboot.
//   * Boot scans the I2C bus and prints what it finds. More than a handful of
//     addresses answering means the bus is floating, not populated.
//
// Two-stage test — the bike's CAN ground reaches the puck through the BEC,
// and USB 5 V collides with the BEC's 5 V on VUSB, so these cannot both be
// connected (README "Reading the bike's CAN bus"):
//
//   Stage 1  USB, CANH/CANL unplugged from the bike. Proves the IMU, the
//            baro and that the TWAI driver installs. Watch it over serial.
//   Stage 2  BEC on, USB out, bike live. The only way to prove frames are
//            actually arriving. Serial is gone, so read it on the phone —
//            the BLE service, UUIDs and packet layout are byte-identical to
//            production, so the Tripper app connects to this build unchanged.
//            GPS fields stay zeroed with the fix bit clear.

#include <Wire.h>
#include <Adafruit_BMP280.h>
#include <NimBLEDevice.h>
#include <Preferences.h>
#include <driver/twai.h>

// ---------- pins & constants ----------
// I2C on the XIAO's default pads. SDA lived on D3 for a while because the
// first board's D4 pad was clamped low — it read 0 even against the internal
// pull-up with nothing attached, so SDA could never idle high and every sensor
// looked dead. That board was replaced and D4 is back in use.
//
// The pad sweep below is what diagnosed it, and it still runs on every boot: a
// pad the chip controls follows both internal pulls, so a clamped one stands
// out against its neighbours. Keeping the sweep is the point of this sketch —
// if the symptom ever comes back, it names the pin in one line.
#define PIN_SDA      D4
#define PIN_SCL      D5
#define CAN_TX_GPIO  GPIO_NUM_7   // D8 -> SN65HVD230 CTX
#define CAN_RX_GPIO  GPIO_NUM_8   // D9 <- SN65HVD230 CRX
#define CAN_STALE_MS 2000UL       // no frame for this long = bus considered dead
#define RETRY_MS     3000UL       // re-probe a missing sensor this often
#define BNO_ADDR     0x28
#define BMP_ADDR     0x76

// BNO055 registers (page 0)
#define BNO_CHIP_ID     0x00
#define BNO_PAGE_ID     0x07
#define BNO_QUA_W_LSB   0x20      // 0x20..0x2D is quat(8) then linear accel(6)
#define BNO_TEMP        0x34
#define BNO_CALIB_STAT  0x35
#define BNO_ST_RESULT   0x36
#define BNO_SYS_STATUS  0x39
#define BNO_SYS_ERR     0x3A
#define BNO_UNIT_SEL    0x3B
#define BNO_OPR_MODE    0x3D
#define BNO_PWR_MODE    0x3E
#define BNO_SYS_TRIGGER 0x3F
#define BNO_ID_EXPECT   0xA0
#define BNO_MODE_CONFIG 0x00
#define BNO_MODE_IMU    0x08      // IMUPLUS: 6-axis, no magnetometer

static const char *SVC_UUID  = "8E7C1A20-0F5A-4B9C-9C90-54B1D2A70001";
static const char *TELE_UUID = "8E7C1A20-0F5A-4B9C-9C90-54B1D2A70002";
static const char *STAT_UUID = "8E7C1A20-0F5A-4B9C-9C90-54B1D2A70003";
static const char *CTRL_UUID = "8E7C1A20-0F5A-4B9C-9C90-54B1D2A70004";

// ---------- packets ----------
// Byte-identical to tripper_puck.ino. Keep them that way: the phone app
// parses by offset, and stage 2 is the only way to see CAN frames arrive.
struct __attribute__((packed)) TelemetryPacket {
  uint8_t  ver;
  uint8_t  flags;        // bit0 fix valid, bit1 time valid — both always 0 here
  uint32_t gpsTimeMs;
  int32_t  lat_e7;
  int32_t  lon_e7;
  int32_t  alt_cm;
  int32_t  baroAlt_cm;
  uint32_t press_pa;
  uint16_t speed_cmps;
  uint16_t course_cdeg;
  uint8_t  sats;
  uint16_t hdop_c;
  int16_t  qw, qx, qy, qz;
  int16_t  linx_mg, liny_mg, linz_mg;
  int16_t  maxG_mg;
  uint8_t  marker;
  uint8_t  canFlags;
  uint16_t canSpeed_dkph;
  uint16_t canRpm;
  uint16_t canPower_w;
  uint16_t canCurrent_da;
  uint16_t canPack_dv;
  uint8_t  canSoc_pct;
  uint16_t canDemand;
  uint16_t cellHi_mv;
  uint8_t  cellHi_idx;
  uint16_t cellLo_mv;
  uint8_t  cellLo_idx;
};
static_assert(sizeof(TelemetryPacket) == 70, "telemetry packet size drifted");

struct __attribute__((packed)) StatusPacket {
  uint8_t  ver;
  uint8_t  fix;
  uint8_t  sats;
  uint8_t  battPct;
  uint16_t hdop_c;
  uint32_t uptime_s;
  int16_t  temp_x10;
  uint8_t  marker;
  uint8_t  reserved;
};
static_assert(sizeof(StatusPacket) == 14, "status packet size drifted");

// ---------- devices ----------
Adafruit_BMP280 bmp(&Wire);
NimBLECharacteristic *chTele = nullptr, *chStat = nullptr;
NimBLEServer *bleServer = nullptr;
Preferences prefs;

bool imuOk = false, bmpOk = false, canOk = false;

// ---------- quaternion ----------
// Adafruit_BNO055 is not linked here, so imu::Quaternion comes with it. This
// is the same math the production firmware runs, spelled out locally.
struct Quat {
  float w = 1, x = 0, y = 0, z = 0;
};

Quat qRef;                              // mount reference; identity until zeroed
Quat lastQuat;
float linX = 0, linY = 0, linZ = 0;     // linear accel, m/s^2
float maxG_g = 0;                       // latched between telemetry packets

Quat qRel() {                           // qRef^-1 (x) q  (unit quat: conj == inverse)
  const float rw = qRef.w, rx = -qRef.x, ry = -qRef.y, rz = -qRef.z;
  const Quat &q = lastQuat;
  Quat o;
  o.w = rw * q.w - rx * q.x - ry * q.y - rz * q.z;
  o.x = rw * q.x + rx * q.w + ry * q.z - rz * q.y;
  o.y = rw * q.y - rx * q.z + ry * q.w + rz * q.x;
  o.z = rw * q.z + rx * q.y - ry * q.x + rz * q.w;
  return o;
}
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

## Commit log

2026-07-21 Tripper-DL1: e-bike BLE telemetry puck — firmware, tools, docs
    Hardware companion for the Tripper iOS app. XIAO ESP32-S3 + BNO055/BMP280
    + u-blox M8 GPS + SSD1306 OLED, streaming 5 Hz telemetry over BLE.
    - tripper_puck: production firmware (BLE service, dual OLED screens,
    marker button, screen hold, 10 s mount-zero persisted to NVS,
    GPS autoconfig at boot)
    - i2c_gate: BNO055 clock-stretch validation (59,722 reads / 0 errors)
    - i2c_diag: I2C wiring diagnostic
    - gps_config_5hz: one-time GPS 5 Hz / 115200 configuration tool
    - build-guide.html: full field guide with decision records
    - README: BLE protocol spec (50-byte telemetry packet layout)
    [gps_config_5hz.ino, i2c_diag.ino, i2c_gate.ino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]
2026-07-21 README: add cable connection diagram
    ASCII wiring diagram matching the XIAO's physical pin columns, rail
    fan-outs for 3V3/GND/I2C, and wiring notes (UART crossover, internal
    pull-ups, Gravity socket, antenna placement).
2026-07-21 Drop the NeoPixel — OLED carries all status
    Remove LED code from tripper_puck (frees D0), update README (BOM,
    pin map, wiring diagram, controls) and build guide accordingly.
2026-07-21 Advertise the service UUID; move the name to the scan response
    The 128-bit service UUID (18 B) and the name (13 B) never both fit in
    the 31-byte primary advertisement, and NimBLE silently dropped the UUID
    — making the puck invisible to Tripper's service-filtered scan (the
    only kind iOS allows in the background) while scanner apps, which scan
    unfiltered, still showed it. UUID now goes in the primary packet and
    the name rides the scan response; iOS merges the two.
    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
2026-07-21 GPS bring-up: survive a BBR loss — ACK-verified reconfig with retries
    A power cycle with a drained backup cell reverts the NEO-M8 to 9600/1 Hz
    factory defaults. The old fallback sent its UBX config blind and the
    module drops the first command after a host baud switch, so the puck
    stayed deaf at 115200 — no time, no sats, no fix, forever (the module
    itself was fixed and tracking the whole time).
    The fallback now confirms NMEA at 9600 before configuring, does only the
    CFG-PRT baud switch on the 9600 link, sets CFG-RATE at 115200 with
    ACK-verified retries, re-saves to BBR (so a healthy cell takes the fast
    path next boot and the "BBR lost" warning only fires on a real cell
    failure), and ret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
    [gps_revert_factory.ino, tripper_puck.ino]
2026-07-21 Buttons on ISRs; never let USB debug prints block the loop; BLE full TX power
    The day's ghost: buttons dead for minutes after some boots, 4 s marker
    lag — but only ever on the bench. Root cause: with the USB CDC port
    half-open (host opened it but isn't draining), every Serial.printf
    blocks until its timeout, freezing the loop for seconds at a time
    (caught live: stall=1761 ms that ended the instant a reader attached).
    Serial.setTxTimeoutMs(0) drops debug bytes instead of waiting — the
    loop can never again gamble on someone reading the port.
    Belt and suspenders: both buttons move to pin-change ISRs with 50 ms
    debounce, so presses latch even mid-stall; the loop just consumes
    counts. Debug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
    [tripper_puck.ino]
2026-07-22 Control opcodes 0x02/0x04: app-triggered zero, ride state with inverted OLED + trip-time screen
    0x02 runs the same mount-zero capture as the button hold, requested from
    the app. 0x04 carries active + elapsed seconds; while active the display
    inverts and a third screen (trip time) joins the 5 s cycle. Elapsed is
    app-authoritative and replayed on reconnect, so link flaps and mid-ride
    reboots resync themselves. Identify's invert is now relative to ride state.
    [tripper_puck.ino]
2026-07-23 Talaria CAN: listen-only sniffer and a DBC verified against real rides
    The bike's bus carries what the puck's own sensors can't see — pack voltage,
    cell balance, motor current, state of charge. This is the bring-up kit; none
    of it is wired into the firmware yet.
    The bus is 250 kbit/s, 11-bit IDs, 15 messages, ~92 frames/s. Everything
    defaults to listen-only: the transceiver never drives the bus and never ACKs,
    so a wrong bitrate can't disturb the controller.
    can_sniff.py drives a Waveshare USB-CAN-A through python-can's seeedstudio
    backend, which speaks the same USB-CAN Analyzer serial protocol. Four modes:
    scan sweeps bitrates, sniff shows decoded values plus a per-byte change map,
    even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
    [can_sniff.py]
2026-07-23 Read the bike's CAN bus on-board; rework the buttons around it
    Moves the CAN work off the USB dongle and into the puck. A 3.3 V SN65HVD230
    on D8/D9 feeds the ESP32-S3's own TWAI controller at 250 kbit/s in
    TWAI_MODE_LISTEN_ONLY — it never transmits and never even ACKs, so no bug
    here can disturb the bike's controller.
    Telemetry grows 50 -> 70 bytes and ver goes to 0x02. The CAN block is
    appended, so every existing offset is unchanged and the app only has to add
    fields: speed, motor rpm, power, current, pack voltage, battery percentage,
    throttle demand, highest and lowest cell with their indices, plus kickstand
    and ride mode packed into a flags byte. The whole block is zeroed and the
    live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
    [can_probe.ino, tripper_puck.ino]
2026-07-23 README: lead with the full wiring schematic
2026-07-23 Docs: match the final wiring — 5 V BEC power, drop SD/battery/switch/LED
    Brings both the README and the build guide in line with the final wiring
    schematic. Power now comes from a 5 V 3 A BEC feeding VUSB (stepped down from
    the bike's pack), not "the bike's USB outlet" — so the USB-vs-bike collision
    warning is now BEC-vs-USB, and the CAN tap's shared ground runs through the
    BEC's negative rail.
    Removes what the e-bike edition no longer has: the microSD module and its
    "Log to SD" build step, CSV format section, and SdFat; the LiPo battery, the
    runtime/charging framing, and the power-budget "outlasts any phone" angle;
    the slide switch; and the NeoPixel with its whole LED-states section. T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
2026-07-24 OLED: probe the I2C address before begin(), so oledOk means something
    Adafruit_SSD1306::begin() never checks for an ACK — it returns true as soon
    as its framebuffer mallocs. So an unplugged display reported "OLED ok" at
    boot and the 2 Hz refresh then pushed a 512-byte frame at an address that
    answers nothing, every frame, forever. Harmless in practice (the address
    byte NACKs and the transfer returns immediately) but it's wasted bus time
    and a banner that lies about the hardware.
    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
2026-07-28 Split the puck across two enclosures: OLED gets its own I2C bus
    The OLED, GPS and buttons move to the handlebar, about a metre of cable
    from the ESP32. Sharing one I2C bus would have dragged the BNO055 — the
    fragile part, the one already forcing the bus to 100 kHz — onto that long,
    capacitive, noisy run. So the buses split: Wire (D4/D5) stays 15 cm long
    inside the rear box with the sensors, Wire1 (D3/D10) carries only the
    display out to the bar. Worst case a bad cable now glitches a screen
    instead of costing sensor fusion.
    can_probe follows the same pins so it works on the assembled hardware.
    Docs pick up the passives the extension needs and the reasoning behind
    each: 2.2k pull-ups siz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
    [tripper-puck.fzz]
2026-07-28 Add SCHEME.ai — the editable source behind the wiring schematic
    The JPG in the README is an export; this is the Illustrator file it comes
    from, so the drawing can be revised rather than re-annotated on top of a
    raster.
2026-07-29 I2C: move SDA to D3 — the D4 pad is clamped low on this XIAO
    D4 reads 0 even against the internal pull-up with nothing attached, so SDA
    can never idle high there and no device can ever signal on it. That presents
    exactly like four dead sensors instead of one bad pad, which is what made it
    worth writing down rather than just moving the wire.
    D3 was free and tests clean: both lines float high, 0x28 and 0x76 enumerate,
    0 bus errors. Wire.begin() now takes the pins explicitly rather than relying
    on the Wire default, and the README pin map, schematic and sketch table follow.
    Also adds bench_imu_can, the bring-up rig that found it — IMU + baro + CAN
    only, no OLED/buttons/GPS. It reads the BN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
    [bench_imu_can.ino, tripper_puck.ino]
2026-07-29 CAN: decode regen level from 0x490 and send it in canFlags
    0x490[0] was recorded as a whole-byte ride-mode echo. It is two fields: bits
    5:3 carry the mode and bits 2:0 the regen level, 1..4. That split is what
    reconciles the 2026-07-23 Eco/Sport toggle (0x09 <-> 0x11) with today's regen
    sweep — 0x09 is Eco+regen1, 0x11 is Sport+regen1 — and explains why the byte
    correlated with mode at r=0.99 while never being only mode.
    Verified over two independent captures and 10 button presses against the dash.
    One sweep ran downward (4->3->2->1) before coming back up, which is what rules
    out a counter that happened to line up with an ascending walk. The selector
    reverses at each end rather than wra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
    [tripper_puck.ino]
2026-07-30 Light and Full builds: split the docs, add tripper_light firmware
    The puck now ships in two configurations. Light is the rear box alone — IMU,
    barometer, bike CAN — in four parts and one enclosure, with the phone supplying
    position and the app acting as the UI. Full adds the handlebar module: 5 Hz GPS,
    the OLED and two buttons. Full is strictly additive: its parts land on D1, D2,
    D6 and D7, which Light leaves free, so upgrading moves nothing already soldered.
    tripper_light drops the GPS, OLED and button code outright rather than fencing
    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
2026-07-30 Docs: what the app must change for the Light build, regen and battPct
    Three things the app currently gets wrong or does not know about yet, written
    up in docs/app-integration.md with byte offsets and the reasoning behind each.
    battPct is a constant, not a reading. There is no battery on this build and no
    fuel gauge, so both firmwares assign 0xFF unconditionally and the app renders
    that as "USB". Production power is the BEC off the traction pack, and USB is
    only ever attached for flashing — never at the same time — so the single state
    that row can display is the one state that should never be true while riding.
    The firmware comment claiming "external USB power" predated BEC power and is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
    [tripper_puck.ino]
2026-07-31 Fix lean angle: apply the mount reference body-side, tilt only
    Lean was unusable. In a 524 s sample ride 48% of straight-line riding
    read |lean| > 10 deg, all 14 right-hand corners reported leaning LEFT,
    and correlation against atan(v*w/g) was -0.52. The bias wandered from
    -1 deg to -30 deg over the ride.
    Both builds run the BNO055 in IMUPLUS, which has no magnetometer, so
    yaw free-runs from wherever the puck pointed at power-on. Yaw error is
    a rotation about the world vertical and so enters on the left
    (q = qYaw(d) (x) qTrue) -- but qRel() applied the mount reference on
    the left too. The drift landed *between* reference and attitude, so the
    reference's tilt no longer cancelled the mount ti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
    [tripper_light.ino, tripper_puck.ino]
2026-08-01 Give the BNO055 its crystal, calibration and a voice
    Lean drifted up to 16 deg on a road GPS showed dead straight, wandering over
    a couple of minutes and snapping back through sharp turns. 7ac31e7 had
    already removed the yaw-drift leak and the ride that prompted this was
    recorded with it flashed, so the remaining error is not the attitude maths.
    Temperature was flat (26.5->26.9 C) and accelerometer noise during the drift
    was *lower* than earlier in the ride, so it is not thermal and not vibration.
    What was never done at all is set the BNO055 up. Both builds called begin()
    and nothing else:
    - setExtCrystalUse(true) was never called, so the fusion ran on the internal
    RC oscillator. Bos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
    [tripper_light.ino, tripper_puck.ino]
2026-08-01 Don't gate the mount zero on a status byte that resets
    Bench-testing the calibration work on real hardware found two faults in it.
    The BNO055's CALIB_STAT reports the fusion algorithm's live confidence, not
    whether calibration offsets are applied. Restoring saved offsets does not
    restore the status byte: a calibrated chip comes up reading accel 0/3 after
    every reset. Gating the mount zero on that meant the zero was refused after
    every power-up -- and on the Light build, which has no buttons and no screen,
    the app would have been the only route and it would have been disabled. That
    is a worse failure than the drift being chased.
    So the firmware now tracks whether it restored offsets from fl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
    [tripper_light.ino, tripper_puck.ino]
2026-08-01 Tell the app whether a mount zero actually landed
    The zero is a fire-and-forget control write: .withoutResponse, no reply, and
    the firmware is allowed to refuse it outright when the IMU is uncalibrated. So
    "the rider tapped the button" and "the puck re-referenced itself" were
    indistinguishable, and three separate failures all looked like success -- the
    control characteristic not yet discovered so the write never happened, the
    notification not landing, and an outright refusal.
    That gap matters most exactly where it is hardest to notice. The Light build
    has no screen and no buttons, so the app is the only thing that can report it,
    and it had nothing to report from.
    So the packet now carries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
    [tripper_light.ino, tripper_puck.ino]
2026-08-03 Put the raw accelerometer on the wire, before the fusion touches it
    The 03-08 ride says lean is still unusable: 2 of 14 corners the right way
    round, -0.20 correlation against atan(v*w/g), and a dead-straight stretch at
    3:50 reading -10 deg for ten seconds while the puck's own gyro says the bike
    isn't rolling at all. Slope is no better -- at 5:53 it reports +1.3 deg
    climbing while the puck's barometer, the phone's barometer and GPS all agree
    the road is dropping.
    Six hypotheses went in and six came out. Not the mount, the axes or the zero:
    at all six standstills roll and pitch return to about 0. Not gyro drift: bias
    is under 0.13 deg/s at rest and the errors come and go rather than accumulat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
    [tripper_light.ino, tripper_puck.ino]
2026-08-07 Record what a direct attitude measurement would take, and correct the slope advice
    Two documents, one new and one wrong.
    direct-attitude-sensing.md answers the question this investigation keeps
    provoking — whether a part can be bought that measures lean and slope rather
    than inferring them. Slope, yes: RTK takes it from about 1.7 degrees to a
    tenth. Lean, not by any single sensor at any price, because an accelerometer
    measures gravity and the bike's own acceleration summed into one vector, and in
    a balanced corner those add up along the bike's own axis. That is not a budget
    problem and no better accelerometer escapes it.
    What does escape it is a second, independent measurement of the veh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
2026-08-08 Firmware v0x05: window-mean gyro/accel, 5 Hz baro, WiFi OTA + diagnostics
    Packet v0x05 (same 86-byte layout): gyro and raw-accel fields now carry
    the mean of the 200 ms window instead of the newest 100 Hz sample; barometer
    read at packet rate instead of 1 Hz. Status packet appends otaState (15 B,
    length-gated).
    WiFi flashing: control write 0x05 raises a per-build SoftAP with ArduinoOTA
    (never survives a power cycle). While up, HTTP serves a status page at / and
    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
2026-08-08 Raw 100 Hz flight recorder, phone flashing, and the slope work behind them
    Record everything, decide later. The telemetry packet averages twenty 100 Hz
    samples into one number, which is right for a live display and wrong for
    analysis: suspension resonance (2-5 Hz) and wheel hop (10-20 Hz) alias into
    the road-grade band at a 5 Hz output rate and can never be separated again.
    A fifth BLE characteristic now ships the samples themselves, batched ten at a
    time behind the PUCK's own millisecond stamp so BLE burst delivery cannot
    corrupt the timeline. Additive: a phone that never subscribes sees no change.
    Flashing from a phone. ArduinoOTA speaks espota, which only the Arduino
    tooling implements,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
    [harness.py, triplib.py, tripper_light.ino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]
2026-08-09 Send the accelerometer's window peak, not just its mean (v0x06)
    The app had a gate it could not trip. Its estimator only takes a "down"
    reference from the accelerometer while |a| is near 1 g — braking bumps and
    drops point it somewhere that isn't down — but it was applying that test to
    the 200 ms window MEAN, the one number structurally incapable of showing a
    jolt inside its own window.
    The first 100 Hz corpus settled it. On the two 2026-08-09 rides the real |a|
    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
2026-08-09 Turn the harness's answer key the right way up, and decode on macOS again
    Two faults in the tools, both of which produce confident wrong answers.
    The harness scored lean against a left-positive kinematic reference, anchored
    on the 2026-08-07 ride. The app flipped to right-positive on 2026-08-08 and
    nothing downstream was told, so the harness marked the CORRECTED app 0/27 on
    a ride where it was right — and would have marked a re-mirrored one perfect.
    Anyone trusting it would have re-broken the sign fix. It now scores 27/27 on
    the same file with no app change.
    Each sign was re-settled against the shipped rollDegrees on both 2026-08-09
    rides rather than from any doc, since it was the docs t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
    [harness.py, triplib.py]
2026-08-10 Let the puck talk back, and find the odometer nobody had looked for (v0x07)
    The puck stops being a read-only instrument. TWAI_MODE_LISTEN_ONLY becomes
    TWAI_MODE_NORMAL in both builds, and two new control opcodes let the app hold
    the bike in a ride mode (0x07) or regen level (0x08).
    0x490 turned out to be a COMMAND from the dash to the motor controller, not the
    echo it had been labelled as for months. Two measurements settled the direction:
    across five button presses 0x490 moved 20-27 ms BEFORE 0x202, and injecting it
    with Eco while the dash went on transmitting Sport drove the controller's demand
    floor 1100 -> 750. The DBC's sender attributions were backwards on both frames
    and are correcte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
    [can_sniff.py, tripper_light.ino, tripper_puck.ino]
2026-08-10 Stand in for the dash: free-run 0x490, derive speed, count our own odometer
    Unplugging the bike's dash takes FIVE frames off the bus with it — proven by
    doing exactly that and diffing the ID list, while every controller and BMS frame
    kept arriving: 0x490 (mode/regen command), 0x303 (speed), 0x402 (odometer),
    0x304 and 0x403. Two of those are things the rider reads, so the puck now
    supplies them.
    The reactive override was right only while a dash was there to reply to. With
    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
